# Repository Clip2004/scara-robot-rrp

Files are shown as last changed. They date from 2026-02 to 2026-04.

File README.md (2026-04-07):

# 🤖 SCARA Robot — Design and Implementation

> Integrative project for **Industrial Robotics** and **Digital Control**  
> Mechatronics Engineering — 8th Semester - EIA University · 2024

---

## 📌 Overview

This repository documents the design, fabrication, and implementation of a **3-DOF SCARA robot (RRP)**: two rotary joints and one prismatic joint. The project was conceived as an automation solution for **TIG welding** tasks, integrating mechanical design, embedded electronics, digital control, and robot kinematics.

The robot is capable of executing a *home* routine, moving to arbitrary points within its workspace, and autonomously following linear and semicircular trajectories.

| | |
|---|---|
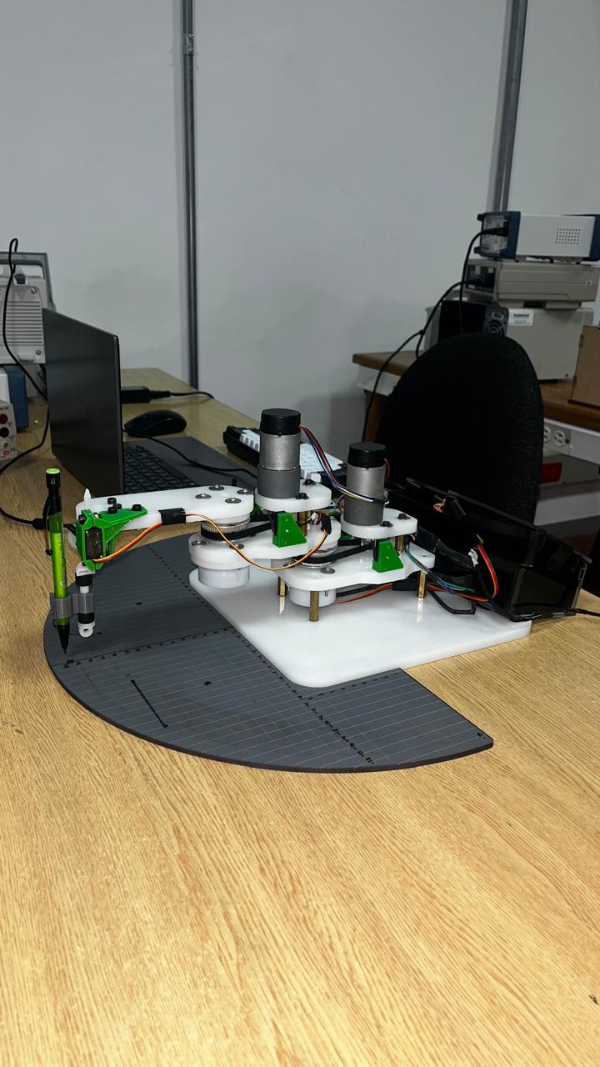
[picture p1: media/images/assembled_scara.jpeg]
Espacio de trabajo
| Robot ensamblado |  |
| CAD | Assembled |

| | |
|---|---|
| **Robot type** | SCARA — RRP (3 DOF) |
| **Target application** | Automated TIG welding |
| **Microcontroller** | Raspberry Pi Pico (MicroPython) |
| **Actuators** | 2× Pololu DC 200 RPM + encoder · 1× MG90S Servo |
| **Year** | 2024 |

---

## 👥 Team

- Mariana Calle Méndez  
- Felipe Jesús Mercado  
- Alejandro Hoyos Chaves  
- Alejandro Blandón Sánchez  

---

## 📁 Repository Structure

```
scara-robot-rrp/
│
├── README.md
├── LICENSE
├── .gitignore
│
├── mechanical/
│   ├── inventor/          # .ipt and .iam files (Autodesk Inventor)
│   ├── stl/               # STL files for 3D printing
│   ├── drawings/          # Technical drawings (PDF / DWG)
│   └── bom.xlsx           # Mechanical bill of materials
│
├── electronics/
│   ├── kicad/             # Full KiCad project
│   ├── gerbers/           # Gerber files for PCB fabrication
│   ├── schematic.pdf      # Exported schematic
│   └── bom_electronics.csv
│
├── firmware/
│   ├── main.py            # Main entry point
│   ├── motors/            # Pololu motor + encoder control
│   ├── servo/             # Servo motor + rack-and-pinion control
│   ├── kinematics/
│   │   ├── forward.py     # Forward kinematics
│   │   ├── inverse.py     # Inverse kinematics
│   │   └── trajectories.py
│   └── config.py          # DH parameters, joint limits, etc.
│
├── control/
│   ├── matlab/            # Simulation and tuning scripts (MATLAB)
│   ├── identification/    # System identification (reaction curve)
│   └── controllers/       # Controller results and coefficients
│
├── docs/
│   ├── dh_parameters.md   # Denavit-Hartenberg parameter table
│   ├── kinematics.md      # Forward and inverse kinematics derivation
│   ├── control_design.md  # Controller design and analysis
│   ├── web/               # Integrated content from project website by section
│   └── wiring_diagram.pdf # Wiring diagram
│
└── media/
    ├── images/            # Photos of the physical robot and web source evidence
    │   └── web/           # Downloaded figures from project website
    └── videos/            # Trajectory demos and final presentation
```

---

## ⚙️ Mechanical Design

The robot was designed in **Autodesk Inventor** and consists of:

- **Joint 1 (R):** Rotary — Pololu DC motor 200 RPM with encoder
- **Joint 2 (R):** Rotary — Pololu DC motor 200 RPM with encoder
- **Joint 3 (P):** Prismatic — MG90S servo motor with rack-and-pinion mechanism (tool holder / TIG torch)

Parts were manufactured at the **metalworking laboratory** using:
- CNC milling and turning
- FDM 3D printing for complex geometry components

---

## 🔌 Hardware & Electronics

A **custom PCB was designed in KiCad**, integrating all power and signal components required for robot operation.

### Main components

| Component | Description |
|---|---|
| Raspberry Pi Pico | Main microcontroller (RP2040) |
| 2× Pololu DC Motor | 200 RPM, 12V, quadrature encoder |
| MG90S Servo | PWM control — Z axis (rack and pinion) |
| L298N | H-bridge motor driver |
| Limit switches | Travel limits and home routine |
| Custom PCB | Designed in KiCad |

Motor supply was set to **12V**, ensuring smooth operation within the optimal range per the Pololu actuator datasheet.

---

## 💻 Firmware

Written in **MicroPython** on the Raspberry Pi Pico. The firmware handles:

- Quadrature encoder reading via interrupts
- Servo PWM control
- Real-time inverse kinematics execution
- Trajectory generation and following
- Homing routine with limit switches
- Serial terminal command interface

### Available commands

| Command | Function |
|---|---|
| `P` | Move to a point (x, y, z) in the workspace |
| `L` | Execute a linear trajectory |
| `C` | Execute a semicircular trajectory |

> ⚠️ **Note:** Being an interpreted language without RTOS support, MicroPython showed timing precision limitations for real-time tasks. Migration to C/C++ is recommended for future versions.

---

## 🌐 Web Integration (2026)

Website content was integrated and organized in `docs/web/` to preserve section-level traceability:

- `docs/web/manufactura.md`
- `docs/web/hardware.md`
- `docs/web/firmware.md`
- `docs/web/instrumentacion.md`
- `docs/web/control.md`
- `docs/web/resultados.md`
- `docs/web/calculos_y_hitos.md`

Supporting image evidence from the website is available in `media/images/web/`.

---

## 📐 Kinematics

### Denavit-Hartenberg Parameters

| Link | θᵢ | dᵢ | aᵢ | αᵢ |
|---|---|---|---|---|
| 1 | θ₁* | 0 | L₁ | 0 |
| 2 | θ₂* | 0 | L₂ | 0 |
| 3 | 0 | d₃* | 0 | 0 |

*Joint variable

### Inverse Kinematics

The analytical solution computes joint angles (θ₁, θ₂) and linear displacement (d₃) from a desired Cartesian position (x, y, z) in the workspace.

---

## 🎛️ Digital Control

Controllers were designed in **MATLAB** using three methodologies:

1. **Reaction Curve** — System identification and empirical tuning
2. **Ultimate Gain (Ziegler-Nichols)** — Based on the system's critical gain
3. **Pole Placement** — Design by pole location in the Z-plane

For each method, controllers were designed for both **angular velocity** and **angular position**, and evaluated through:

- Closed-loop step response
- Stability analysis on the unit circle
- Discrete-time Root Locus
- Gain and phase margins (discrete Bode diagram)

### Selected controllers

| Variable | Controller | Method |
|---|---|---|
| Angular velocity | **PI** | Pole Placement |
| Angular position | **PD** | Pole Placement |

Selection was based on strict relative stability criteria: controllers with poles near or outside the unit circle, or with insufficient gain/phase margins, were discarded.

---

## 📊 Results

- ✅ Functional home routine with limit switches
- ✅ Point-to-point positioning within the workspace
- ✅ Linear trajectory implemented and validated
- ✅ Semicircular trajectory implemented and validated
- ✅ Small position errors and good repeatability

### Key conclusions

- A solid mechanical design is critical: it reduces backlash, simplifies control, and improves end-effector precision.
- Encoder noise was the main electronics challenge. A moving average filter was implemented, though its performance was limited.
- MicroPython was functional for the prototype, but its timing limitations are evident in high-precision applications.

---

## 🔮 Future Work

- [ ] Migrate firmware to **C/C++** (compiled language, better real-time performance)
- [ ] Implement a **digital low-pass filter** for encoder reading
- [ ] Add **higher gear ratios** to improve position control resolution
- [ ] Integrate a graphical interface for trajectory programming
- [ ] Validate with a real TIG torch for automated welding

---

## 🛠️ Tools Used

| Area | Tool |
|---|---|
| Mechanical design | Autodesk Inventor |
| PCB design | KiCad |
| Programming | MicroPython (Raspberry Pi Pico) |
| Simulation & control | MATLAB / Simulink |
| Manufacturing | CNC · FDM 3D Printing |

---

## 📄 License

This project was developed for academic purposes. See the [LICENSE](LICENSE) file for details.

---

> 🌐 Project website: [alejoblandon22.wixsite.com/robot-scara](https://alejoblandon22.wixsite.com/robot-scara)

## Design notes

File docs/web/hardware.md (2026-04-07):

# Hardware (fuente web)

Fuente principal: https://alejoblandon22.wixsite.com/robot-scara/blank-3
Fecha de integracion: 2026-04-06

## Arquitectura de hardware

El sitio reporta un sistema compuesto por actuadores, sensores, etapa de potencia y microcontrolador. La plataforma central es Raspberry Pi Pico (RP2040), con dos motores Pololu con encoder para articulaciones rotacionales y un servomotor MG90S para el eje prismativo de herramienta.

## Elementos funcionales

- Microcontrolador: Raspberry Pi Pico
- Actuadores: 2 motores Pololu 200 RPM + 1 servo MG90S
- Driver: L298N para control de motores DC
- Sensores: encoders y finales de carrera
- Interconexion: PCB propia y esquema de conexion

## Criterio de alimentacion

Se menciona operacion a 12V para la etapa de motores, buscando equilibrio entre desempeno, costo y facilidad de implementacion.

## Evidencia en la web

La pagina incluye bloques de PCB, esquema y conexion, junto con un diagrama grafico de conexiones de hardware.

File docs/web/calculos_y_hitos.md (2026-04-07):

# Calculos, derivaciones y hitos del desarrollo (integracion)

Fuentes:
- https://alejoblandon22.wixsite.com/robot-scara
- https://alejoblandon22.wixsite.com/robot-scara/about-3
- https://alejoblandon22.wixsite.com/robot-scara/copia-de-arquitectura-firmware-hardware
Fecha de integracion: 2026-04-06

## Donde estan los calculos en el repositorio

La web publica una vista general del proyecto, mientras que el detalle matematico se conserva en documentos tecnicos del repositorio:

- docs/dh_parameters.md
- docs/kinematics.md
- docs/control_design.md

## Trazabilidad tecnica

La narrativa web y los documentos locales son consistentes en los siguientes puntos:

- Modelo SCARA RRP de 3 GDL
- Integracion de cinemativa directa/inversa para trayectorias
- Control de posicion y velocidad angular
- Validacion experimental con rutinas home, lineal y semicircular

## Hitos del desarrollo (resumen)

1. Definicion del problema de automatizacion para soldadura.
2. Diseno mecanico preliminar y seleccion de arquitectura SCARA.
3. Integracion de hardware (motores, encoders, Pico, driver, limites).
4. Implementacion de firmware y comandos C/L/P.
5. Ajuste de control para posicion y velocidad.
6. Validacion final con trayectorias y reporte de conclusiones.

## Nota

Este archivo funciona como puente entre el contenido descriptivo del sitio web y los documentos matematicos detallados ya presentes en el repositorio.

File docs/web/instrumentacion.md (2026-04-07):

# Instrumentacion (fuente web)

Fuente principal: https://alejoblandon22.wixsite.com/robot-scara/copia-de-fabricaci%C3%B3n
Fecha de integracion: 2026-04-06

## Componentes de instrumentacion

El sitio describe una instrumentacion enfocada en seguridad de movimiento y retroalimentacion:

- 4 finales de carrera para limites mecanicos
- 2 motores Pololu como base de actuacion de articulaciones
- Sensado por encoder para estimacion de posicion y velocidad

## Objetivo de la instrumentacion

La seleccion de elementos busca operacion autonoma confiable, deteccion de limites fisicos y continuidad de control durante ejecucion de trayectorias.

## Evidencia multimedia en origen

La pagina presenta una galeria de elementos y una tabla de componentes. Parte de esa evidencia visual se integra en media/images/web para respaldo local del repositorio.

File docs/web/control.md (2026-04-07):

# Control (fuente web)

Fuente principal: https://alejoblandon22.wixsite.com/robot-scara/about-3
Fecha de integracion: 2026-04-06

## Operacion del sistema

La seccion enfatiza control de dos variables ligadas: posicion y velocidad angular. Se plantea una estrategia de ajuste iterativo para alcanzar un punto de operacion estable, con restricciones de seguridad y calidad de trayectoria.

## Posicion

La posicion se considera variable critica e inestable, por lo que se requiere control preciso y respeto de limites fisicos de recorrido definidos por finales de carrera y geometria mecanica.

## Velocidad angular

Se prioriza evitar aceleraciones abruptas y cambios bruscos que puedan afectar calidad de soldadura, rebotes mecanicos o seguridad de operacion.

## Criterios de diseno en la pagina

- Suavidad de movimiento
- Seguridad del operador
- Cumplimiento de limites mecanicos
- Ajuste independiente por variable para converger a operacion robusta

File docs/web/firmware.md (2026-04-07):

# Firmware (fuente web)

Fuente principal: https://alejoblandon22.wixsite.com/robot-scara/projects-6
Fecha de integracion: 2026-04-06

## Plataforma y alcance

El firmware fue implementado sobre Raspberry Pi Pico usando MicroPython para pruebas de laboratorio, validacion de rutinas y ejecucion de trayectorias.

## Funciones operativas reportadas

- Rutina de referencia (home)
- Movimiento a punto dentro del workspace
- Trayectoria lineal
- Trayectoria semicircular
- Uso de finales de carrera para seguridad de limites

## Interfaz de comandos

La pagina describe tres comandos principales:

- C: trayectoria semicircular
- L: trayectoria lineal
- P: ir a punto del workspace

## Limitaciones observadas

El contenido de resultados del sitio indica que MicroPython, al ser interpretado y sin RTOS, presenta limitaciones para tareas con temporizacion estricta y multitarea de alta exigencia.

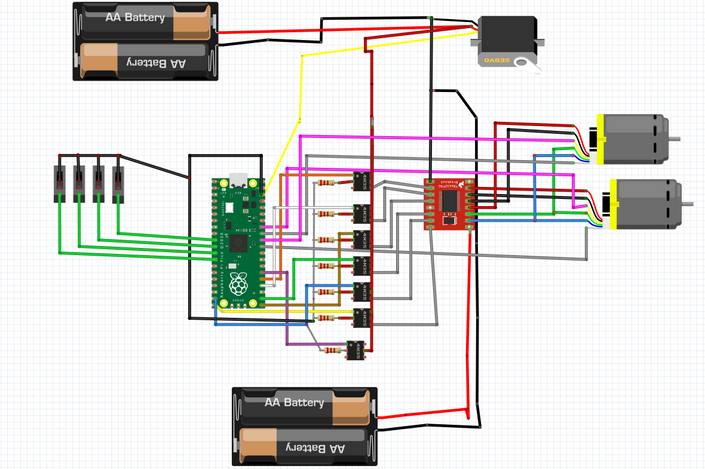
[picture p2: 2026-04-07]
media/images/web/hardware_conexion.png

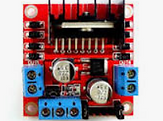
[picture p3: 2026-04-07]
media/images/web/instrumentacion_elemento_02.png

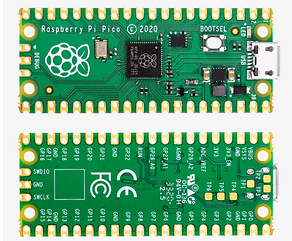
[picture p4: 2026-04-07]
media/images/web/instrumentacion_elemento_04.png

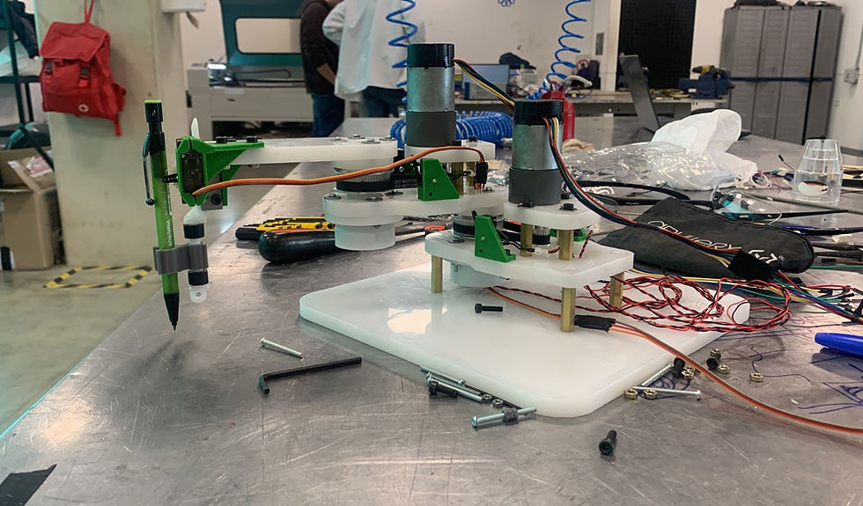
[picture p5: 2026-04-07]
media/images/web/inicio_portada.jpg

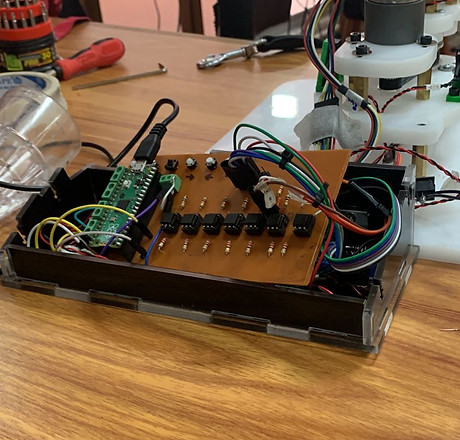
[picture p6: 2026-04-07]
media/images/web/inicio_escena.jpg

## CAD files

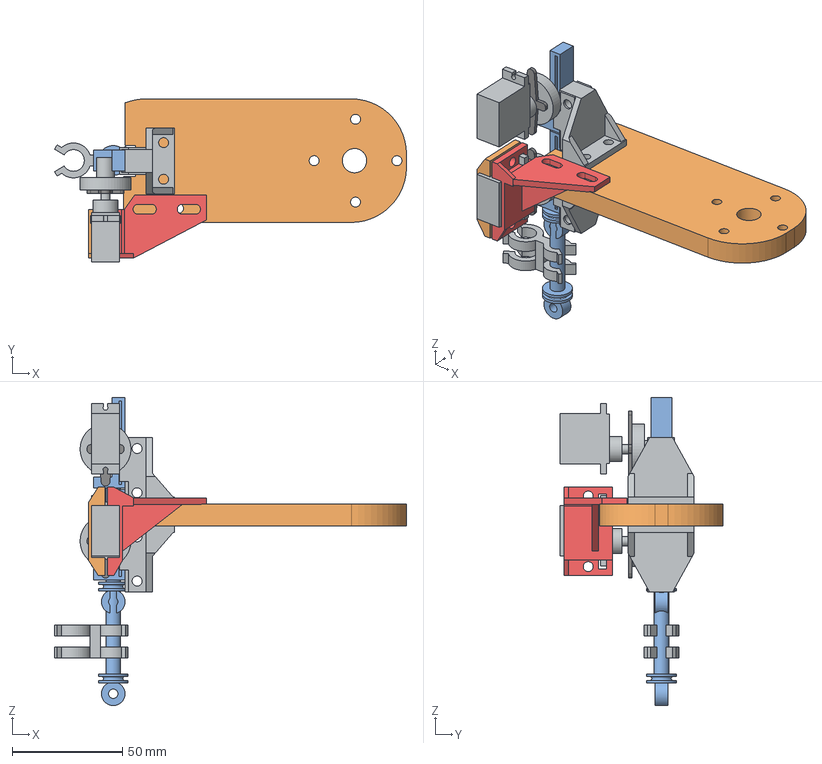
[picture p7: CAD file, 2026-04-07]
mechanical/stl/ensamble_herramienta.stp
159.4 x 73.9 x 139.5 mm
lamina_herrAMIENTA
servomotor x 2
acople_servo x 2
cremallera1 x 2
polea_ensayo x 2
lamina-1 - copia x 4
soporte_pinza x 2
soporte-motor
soprte_motor

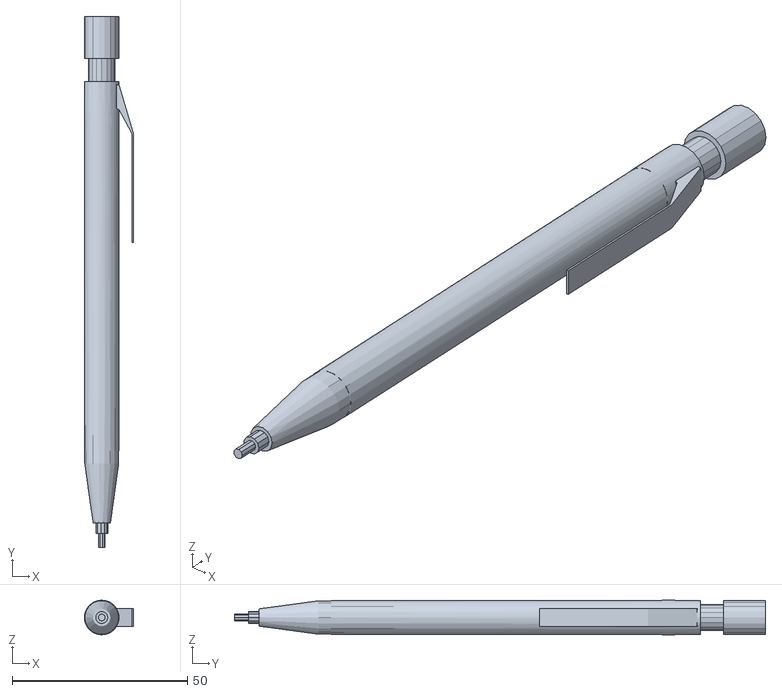
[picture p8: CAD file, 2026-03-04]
control/matlab/stl/lapiz.stl
14.0 x 151.6 x 9.90

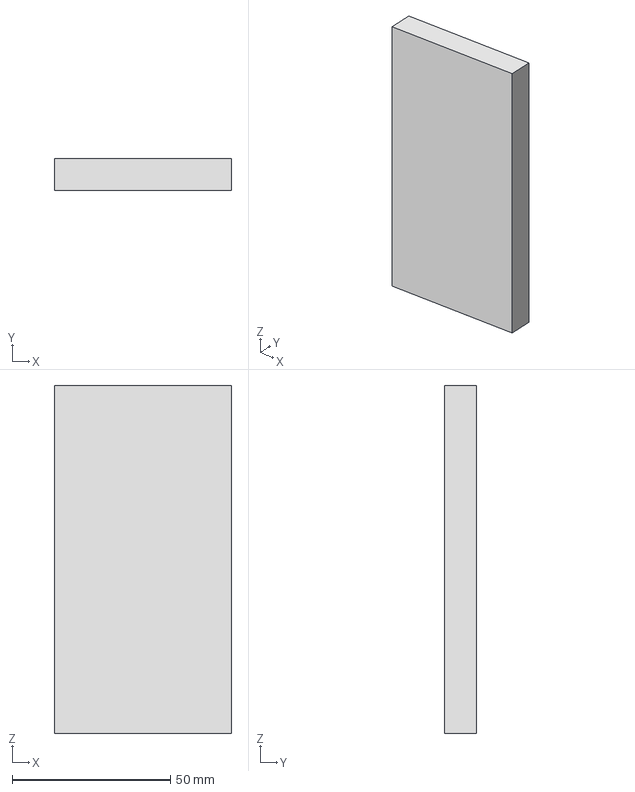
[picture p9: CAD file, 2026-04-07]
mechanical/stl/prueba.stp
56.0 x 10.0 x 110.0 mm

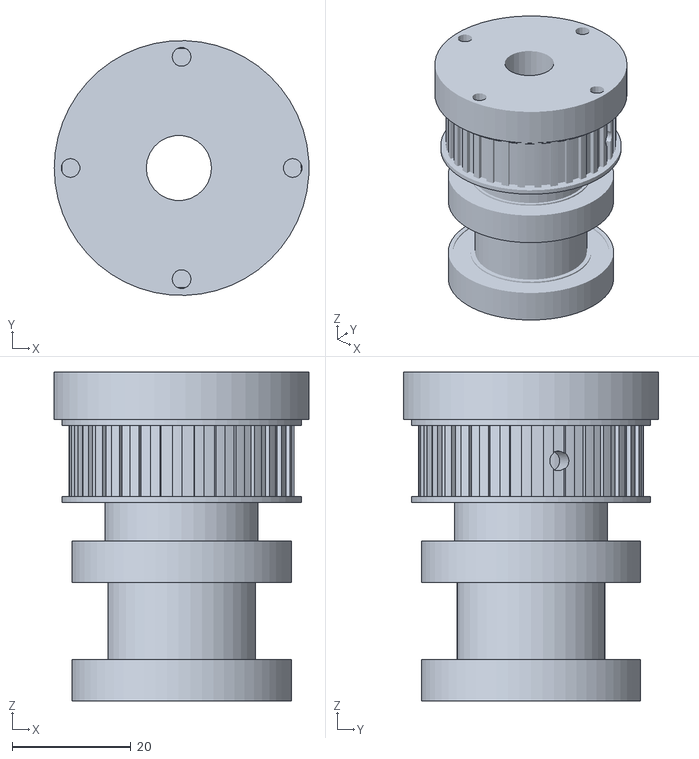
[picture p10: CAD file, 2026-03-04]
control/matlab/stl/eje.stl
43.0 x 43.0 x 55.5

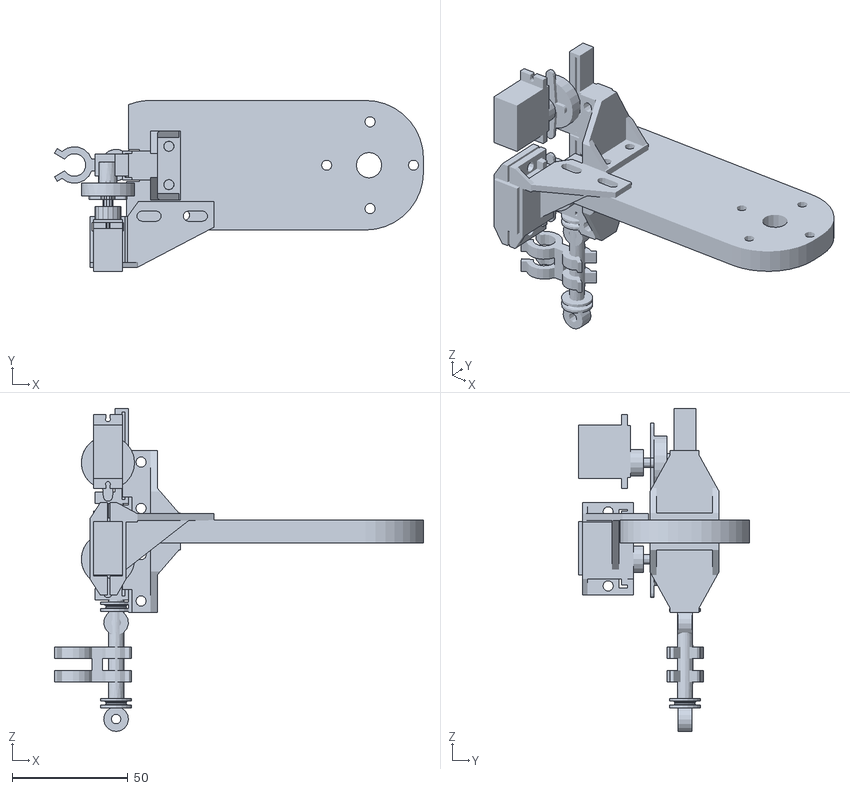
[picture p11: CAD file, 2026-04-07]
mechanical/stl/base_herramienta.stl
159.4 x 73.9 x 139.5

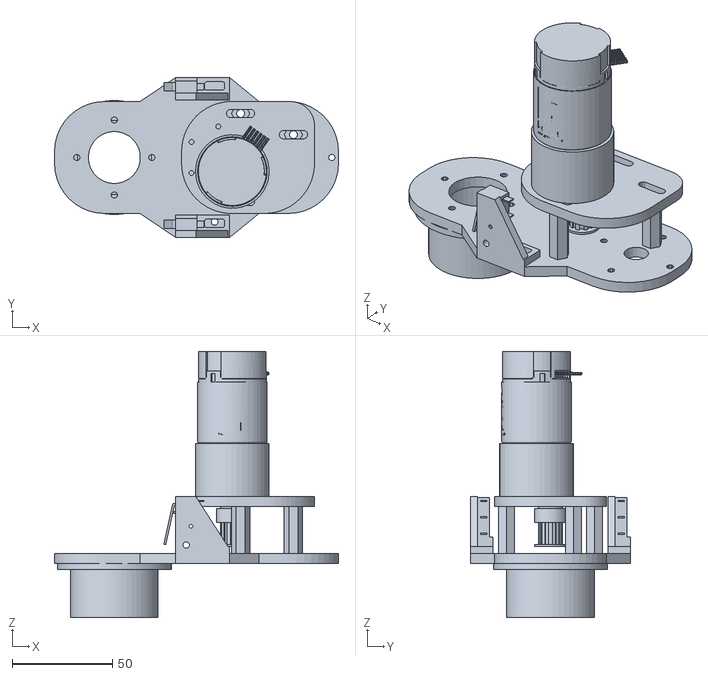
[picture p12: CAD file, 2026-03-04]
control/matlab/stl/base_motor_2.stl
142.0 x 80.0 x 133.2

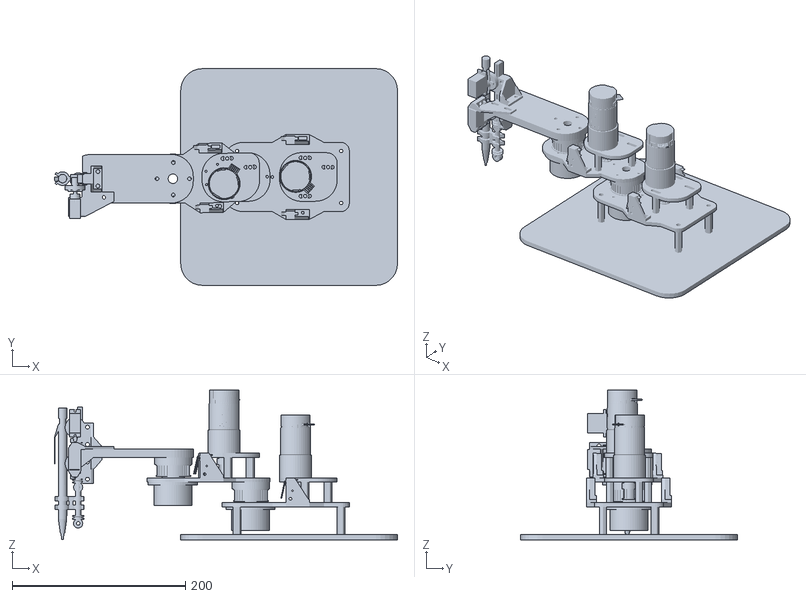
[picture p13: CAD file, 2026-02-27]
mechanical/stl/SCARA.stl
395.6 x 250.0 x 172.7

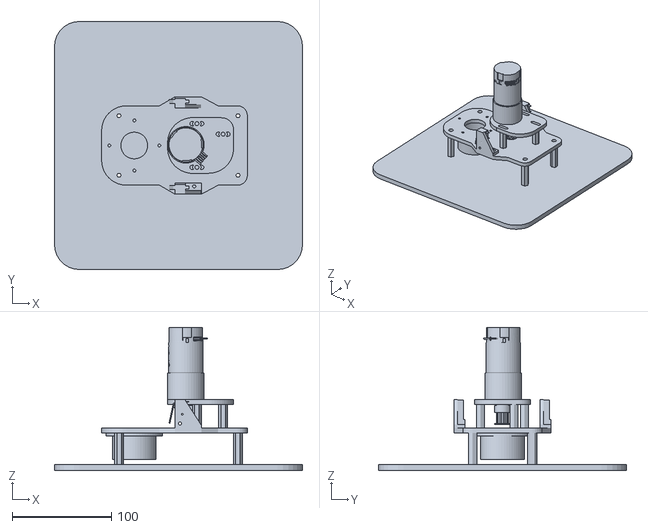
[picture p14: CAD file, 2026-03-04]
control/matlab/stl/base_motor_1.stl
250.0 x 250.0 x 144.2

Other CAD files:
control/matlab/stl/base_herramienta.stl
mechanical/inventor/BaseMotor1.iam
mechanical/inventor/BaseSuperior.iam
mechanical/inventor/BaseSuperior_final.iam
mechanical/inventor/acople_servo.ipt
mechanical/inventor/base.ipt
mechanical/inventor/base_final.iam
mechanical/inventor/base_herramienta.iam
mechanical/inventor/base_herramienta.ipt
mechanical/inventor/cremallera1.ipt
mechanical/inventor/eje.iam
mechanical/inventor/eje_25.ipt
mechanical/inventor/ensamble_final.iam
mechanical/inventor/ensamble_herramienta.iam
mechanical/inventor/final_2.ipt
mechanical/inventor/final_carrera.iam
mechanical/inventor/herramienta.iam
mechanical/inventor/herramienta_final.iam
mechanical/inventor/lamina-1 - copia.ipt
mechanical/inventor/lamina_herrAMIENTA.ipt
mechanical/inventor/lamina_inferior.ipt
mechanical/inventor/lamina_motor_superior.ipt
mechanical/inventor/lamina_superior.ipt
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

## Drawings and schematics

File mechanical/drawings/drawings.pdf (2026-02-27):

4,2
1,3

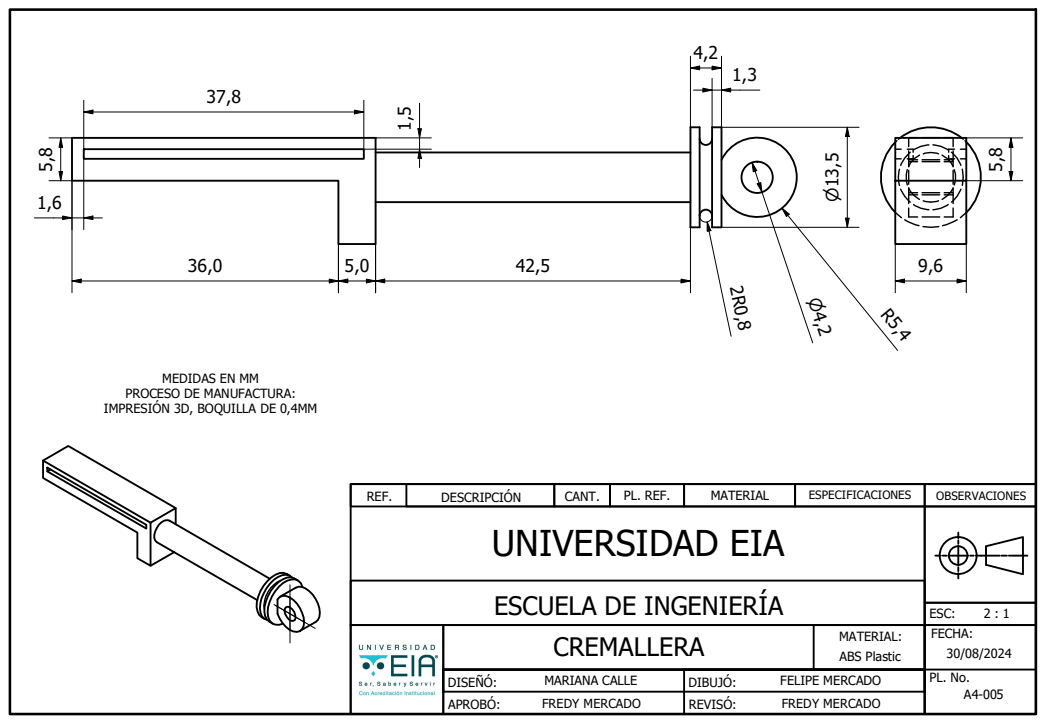
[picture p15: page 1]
UNIVERSIDAD EIA; REF.; DESCRIPCIÓN; CANT.; PL. REF.; MATERIAL; ESPECIFICACIONES; OBSERVACIONES; ESC:; FECHA:; DISEÑÓ:; APROBÓ:; DIBUJÓ:; REVISÓ:; MAR; PL. No. IANA CALLE; FREDY MERCADO; FELIPE MERCADO; MATERIAL:; CREMALLERA; ABS Plastic

MEDIDAS EN MM
PROCESO DE MANUFACTURA:
IMPRESIÓN 3D, BOQUILLA DE 0,4MM

ESCUELA DE INGENIERÍA

142,0

18,8 | 49,0

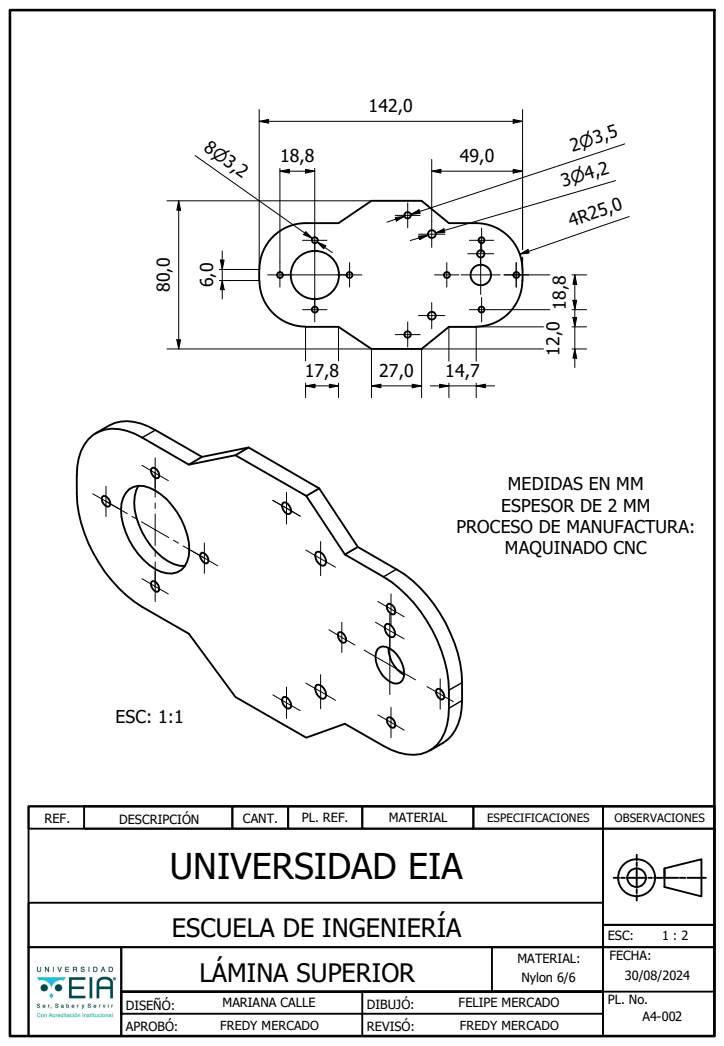
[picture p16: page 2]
UNIVERSIDAD EIA; REF.; DESCRIPCIÓN; CANT.; PL. REF.; MATERIAL; ESPECIFICACIONES; OBSERVACIONES; ESC:; FECHA:; DISEÑÓ:; DIBUJÓ:; MAR; PL. No. IANA CALLE; FELIPE MERCADO; MATERIAL:; Nylon 6/6; ESC: 1:1

MEDIDAS EN MM
ESPESOR DE 2 MM
PROCESO DE MANUFACTURA:
MAQUINADO CNC

ESCUELA DE INGENIERÍA
LÁMINA SUPERIOR

5,0
15,4

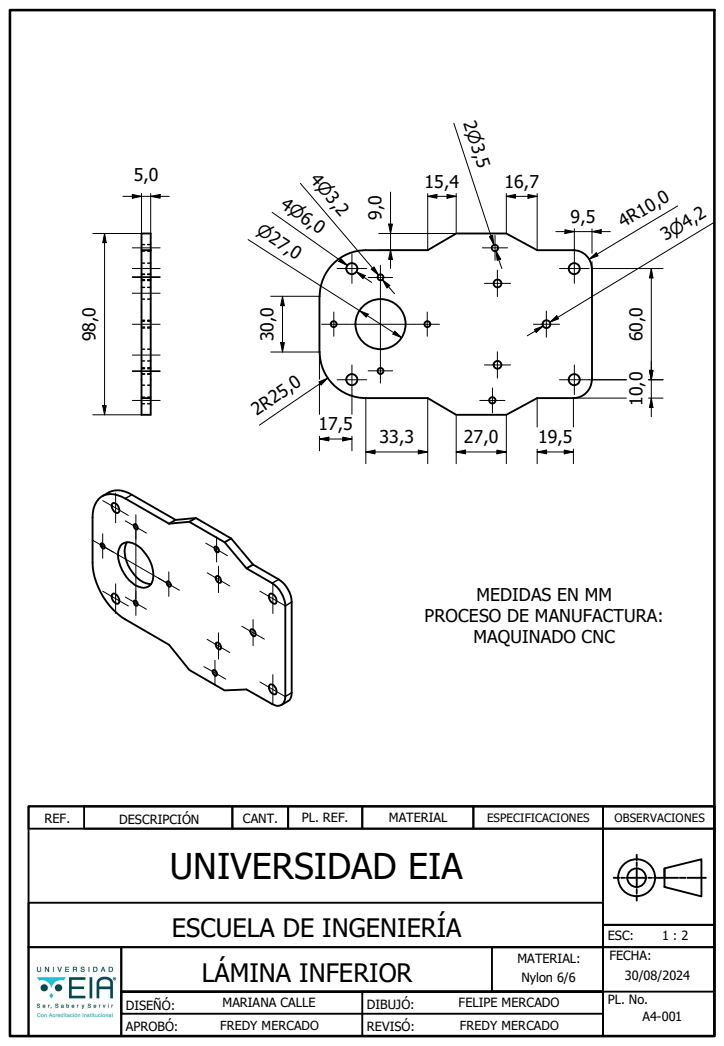
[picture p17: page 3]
UNIVERSIDAD EIA; REF.; DESCRIPCIÓN; CANT.; PL. REF.; MATERIAL; ESPECIFICACIONES; OBSERVACIONES; ESC:; FECHA:; MATERIAL:; Nylon 6/6

MEDIDAS EN MM

PROCESO DE MANUFACTURA:
MAQUINADO CNC

ESCUELA DE INGENIERÍA
LÁMINA INFERIOR

5,0

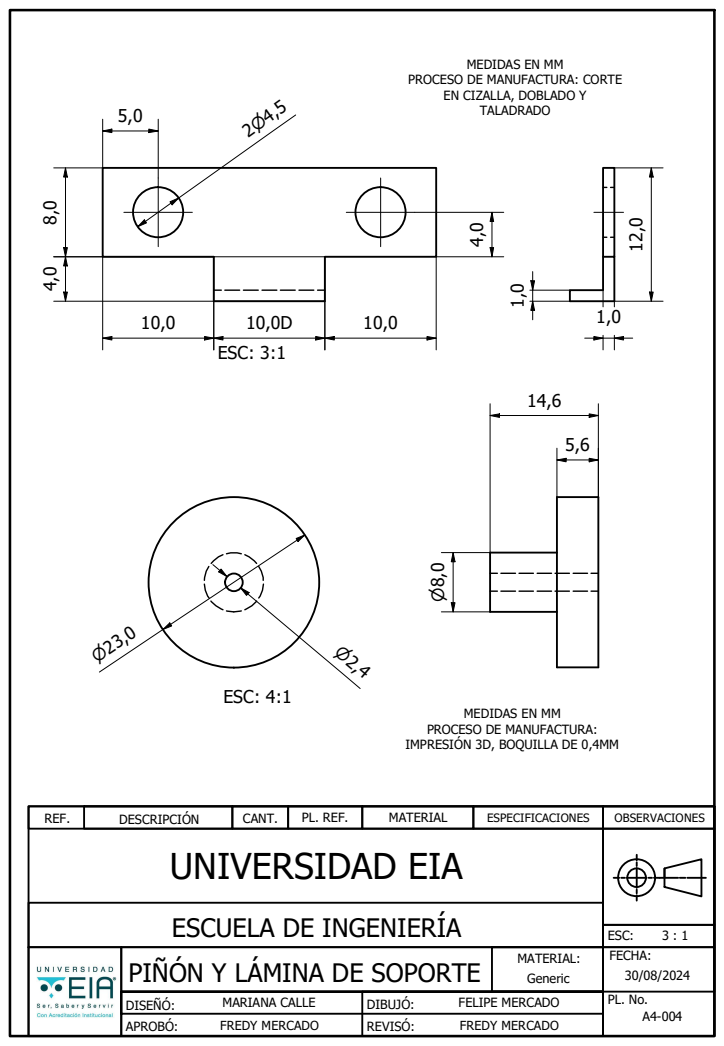
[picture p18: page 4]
UNIVERSIDAD EIA; REF.; DESCRIPCIÓN; CANT.; PL. REF.; MATERIAL; ESPECIFICACIONES; OBSERVACIONES; ESC:; FECHA:; MATERIAL:; Generic; ESC: 3:1; ESC: 4:1

MEDIDAS EN MM

PROCESO DE MANUFACTURA: CORTE
EN CIZALLA, DOBLADO Y
TALADRADO

PROCESO DE MANUFACTURA:
IMPRESIÓN 3D, BOQUILLA DE 0,4MM

ESCUELA DE INGENIERÍA
PIÑÓN Y LÁMINA DE SOPORTE

3,0

10,8

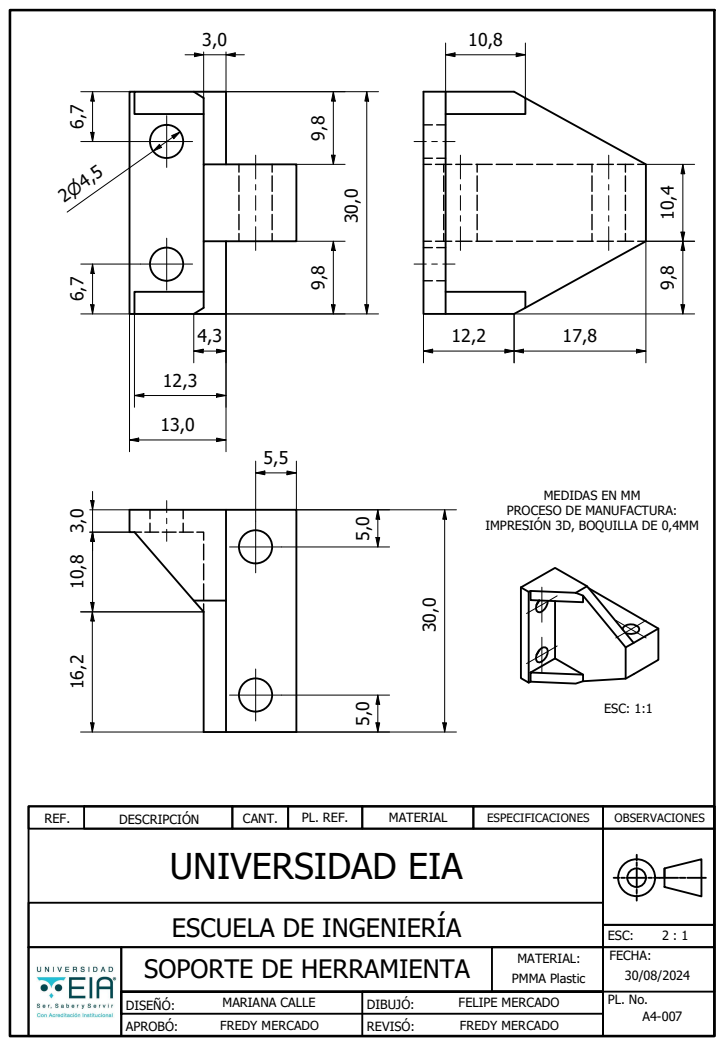
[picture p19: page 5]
UNIVERSIDAD EIA; REF.; DESCRIPCIÓN; CANT.; PL. REF.; MATERIAL; ESPECIFICACIONES; OBSERVACIONES; ESC:; FECHA:; MATERIAL:; PMMA Plastic; ESC: 1:1

MEDIDAS EN MM
PROCESO DE MANUFACTURA:
IMPRESIÓN 3D, BOQUILLA DE 0,4MM

ESCUELA DE INGENIERÍA

SOPORTE DE HERRAMIENTA

37,2
14,0 | 5,0

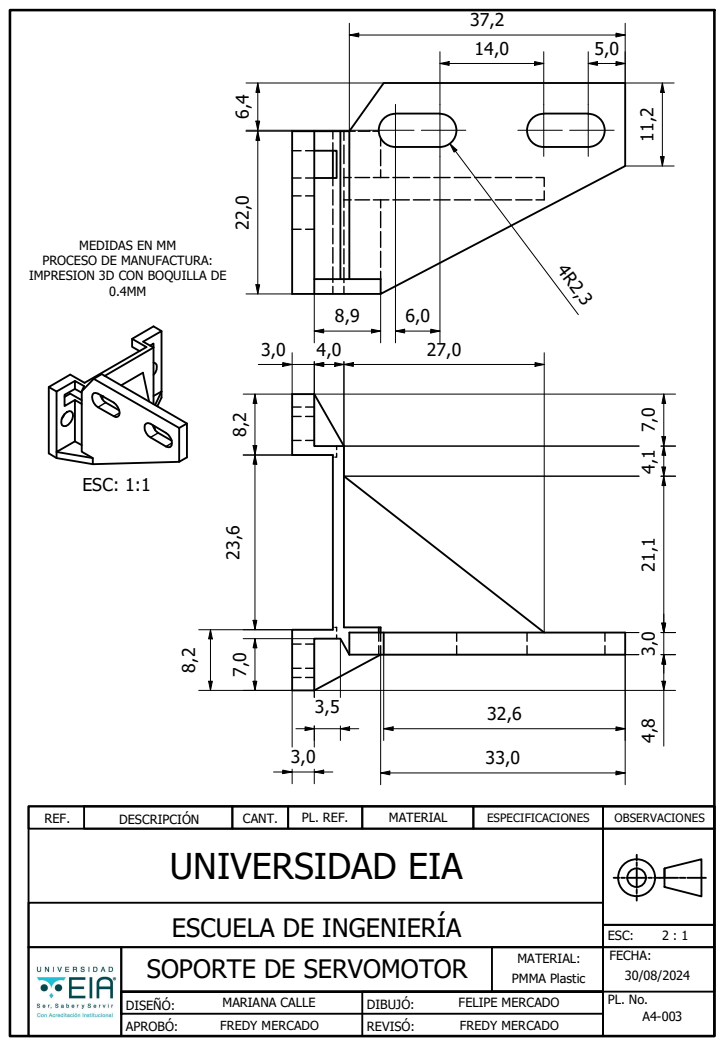
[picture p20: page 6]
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

MEDIDAS EN MM
PROCESO DE MANUFACTURA:
IMPRESION 3D CON BOQUILLA DE

ESCUELA DE INGENIERÍA

SOPORTE DE SERVOMOTOR

2X4,0

2X4,4

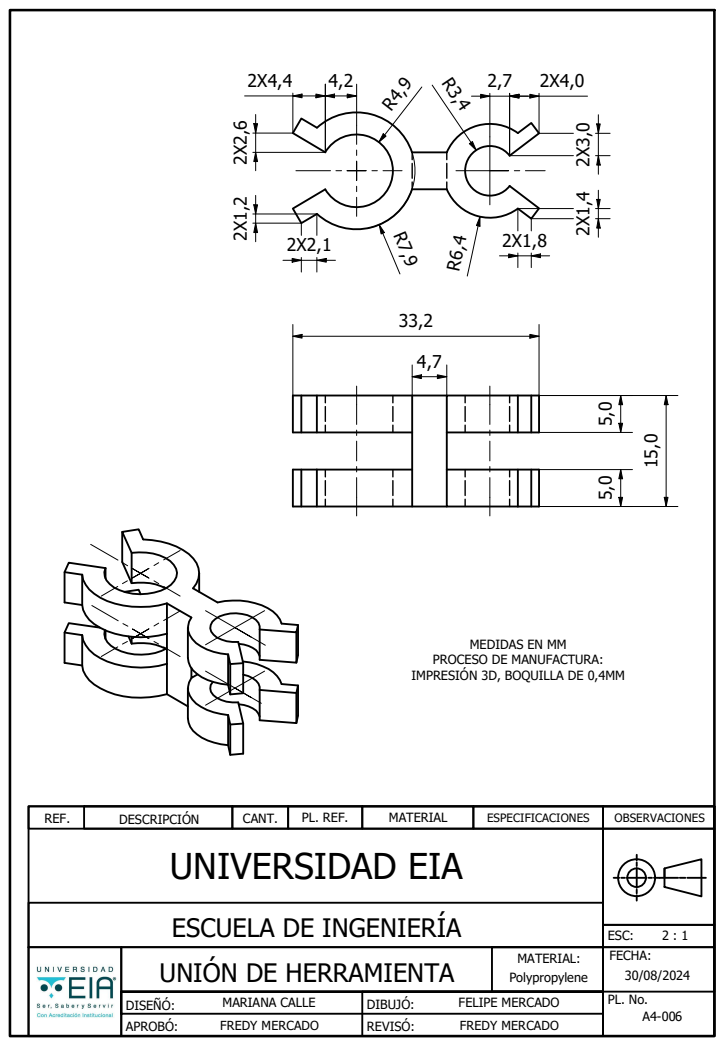
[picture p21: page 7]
UNIVERSIDAD EIA; REF.; DESCRIPCIÓN; CANT.; PL. REF.; MATERIAL; ESPECIFICACIONES; OBSERVACIONES; ESC:; FECHA:; MATERIAL:; Polypropylene

MEDIDAS EN MM
PROCESO DE MANUFACTURA:
IMPRESIÓN 3D, BOQUILLA DE 0,4MM

ESCUELA DE INGENIERÍA
UNIÓN DE HERRAMIENTA

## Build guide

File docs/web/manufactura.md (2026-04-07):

# Manufactura (fuente web)

Fuente principal: https://alejoblandon22.wixsite.com/robot-scara/blank-1
Fecha de integracion: 2026-04-06

## Objetivo de manufactura

La seccion de manufactura describe el enfoque para construir un robot SCARA orientado a aplicaciones de soldadura. El criterio de diseno prioriza tres variables: alcance geometrico, precision del efector final y comportamiento velocidad/posicion durante la operacion.

## Enfoque de construccion

Se reporta una estrategia de fabricacion enfocada en viabilidad academica y reproducibilidad de laboratorio. La estructura mecanica fue planteada para facilitar ensamblaje, mantenimiento y pruebas de trayectorias sobre piezas de practica.

## Relacion con la aplicacion

La manufactura se conecta con el caso de uso de soldadura MIG/TIG: un diseno mecanico estable reduce error acumulado, mejora repetibilidad y simplifica la etapa de control.

## Enlaces relevantes de la seccion

- Planos y ensamble: pagina enlazada desde MANUFACTURA
- Fabricacion: pagina enlazada desde MANUFACTURA
- Referencia externa citada en el sitio: maquituls.es (contexto de soldadura)

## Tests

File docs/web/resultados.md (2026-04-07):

# Resultados y recomendaciones (fuente web)

Fuente principal: https://alejoblandon22.wixsite.com/robot-scara/copia-de-arquitectura-firmware-hardware
Fecha de integracion: 2026-04-06

## Logros reportados

Para la entrega final se reporta cumplimiento de objetivos del proyecto integrador: robot SCARA 3 GDL con rutina home, trayectoria lineal, trayectoria semicircular y movimiento a puntos en el workspace.

## Conclusiones tecnicas destacadas

- Un buen diseno mecanico simplifica control y mejora precision de posicion.
- El ruido en lectura de encoder fue un reto importante para calidad de medicion.
- MicroPython cumple para prototipo academico, pero no es ideal para requisitos de temporizacion estricta.
- El trabajo interdisciplinario fue clave para cerrar el proyecto con resultados funcionales.

## Recomendaciones futuras

- Migrar firmware a C/C++ para mayor rendimiento temporal.
- Reemplazar o complementar filtro de media movil con filtrado digital pasa-bajas.
- Usar mayor relacion de transmision para mejorar resolucion de posicion.

## Evidencia visual de la seccion

La pagina presenta imagenes de diseno final, area de trabajo y recorrido programado.

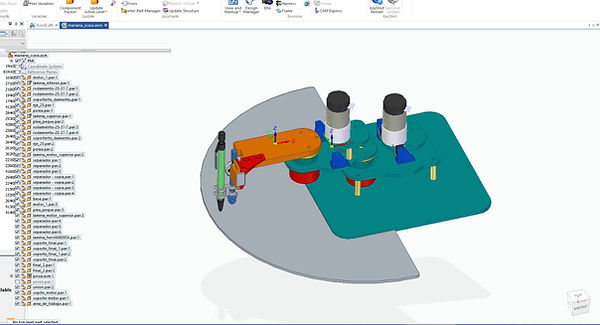
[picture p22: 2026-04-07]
media/images/web/resultados_zona_trabajo.jpg

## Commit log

2026-02-27 mechanical ready
    [BaseMotor1.iam, BaseSuperior.iam, BaseSuperior_final.iam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]
2026-03-04 changes before clone
    [base_herramienta.stl, base_motor_1.stl, base_motor_2.stl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]
2026-04-07 Digital Twin almost there!
    [base_herramienta.0003.iam, base_herramienta.iam, base_herramienta.ipt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]
2026-04-07 chore: clean repository artifacts and update ignore rules
    [base_herramienta.0003.iam, ensamble_herramienta.0004.iam, herramienta.0002.iam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]
